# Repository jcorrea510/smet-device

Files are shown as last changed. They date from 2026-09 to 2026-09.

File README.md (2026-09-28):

# SMET rev3: parametric CadQuery rebuild

`SMET_rev3_assembly.stl` is a mesh of the whole simple-machines marble tower, with no CAD source.
`smet_rev3_assembly.py` rebuilds it as an editable CadQuery model. All dimensions are variables in
millimetres at the top of the file.

```bash
pip install -r requirements.txt
python smet_rev3_assembly.py   # writes output/smet_rev3_assembly.step and .stl
python compare.py              # checks the rebuild against the original, writes renders/
python motion_check.py         # collision + motion check for the wedge and the wheel & axle
```

* `output/smet_rev3_assembly.step`: 59 named, coloured parts (60 solids, because `fork_wheel` is two
  uprights). Import it into Onshape.
* `output/smet_rev3_assembly.stl`: one mesh for slicing and printing.
* `renders/`: side-by-side previews (original STL = blue, updated design = orange), the labelled
  `wedge_detail.png` and `winch_detail.png`, and `comparison_report.txt`.

## What's in the model

The tower is 312.0 × 304.8 × 757.0 mm overall (X × Y × Z). The base is 304.8 mm (12 in) square, and
marble 1 (arriving from the previous group) overhangs the left edge by 7.2 mm. The machines, top to bottom:

| Simple machine  | Parts |
|---|---|
| Pulley | `pulley` spool on `pulley_axle`, held by `pulley_arm` |
| Wedge | `wedge`, hung from the pulley string and jammed into the `top_ramp` (see below) |
| Screw | `spiral_upper` / `spiral_lower`: a 2-turn helical channel on three ¼ in dowels |
| Inclined planes | `entry_ramp`, `top_ramp`, `transfer_chute`, 6 `zigzag_ramp_*` |
| Wheel & axle | `paddle_wheel` + `string_drum` on a shared `wheel_axle`: a winch that tips the seesaw (see below) |
| Levers | `seesaw`, the counter-weighted `lever`, the tipping `cradle` + `rocker`, and the hinged `trapdoor` |

Every straight ramp shares one U-channel profile: 25.4 mm wide, 2 mm walls, 3.2 mm floor, walls 10 mm tall.

## How the machine runs

1. **Marble 1** comes from the previous group. It rolls down the `entry_ramp` (inclined plane) from the
   left edge of the base onto the `trapdoor` (lever).
2. The trap door tips and pulls a string over the `pulley` at the top. The other end of that string holds
   the `wedge`, which is jammed into the `top_ramp` in front of **marble 2**. The pull yanks the wedge up
   out of the ramp.
3. Marble 2 rolls down the `spiral` (screw), the `transfer_chute` and the six `zigzag_ramp`s (inclined
   planes).
4. Marble 2 drops into a cup on the **wheel & axle** and stays there. Its weight turns the wheel, and a
   drum on the same axle winds up a string that lifts the left end of the `seesaw` (lever).
5. The seesaw tips, and **marble 3**, which was waiting on it, rolls off onto the counter-weighted `lever`.
   That tips it into the `cradle` at the right edge, which hands it to the next group.

Each machine moves the next one. Marble 1 runs the trap door, which runs the pulley, which pulls the
wedge. Marble 2 runs the wheel & axle, which moves the seesaw.

## Redesign 1: the wedge (`VERTICAL_WEDGE`)

In the original, the wedge sat loose on the ramp floor, so it didn't really work as a wedge. Now it is a
small wooden wedge (12 mm thick, 20 mm tall, 17 mm wide at the bottom and 27 mm at the top) that hangs
straight down from the pulley string. Its sloping sides are jammed into the top ramp against the top
edges of the two side walls, and its flat face holds marble 2 back.

When marble 1 tips the trap door, the trap door drops about 22° onto its stop and pulls the string down
about 21 mm. The wedge only needs to rise about 15 mm to clear marble 2. Even fully raised, it still
stops about 2.5 mm below the pulley.

The wedge's weight is what holds the trap door level until marble 1 arrives. A wooden wedge on its own
(about 2.6 g) is too light for that. So there is a stack of washers (`wedge_weight`) on its string,
where the original design had a disc. **Tune it by hand:** add washers until the trap door stays up by
itself, then check that marble 1 still tips it. If the trap door is printed solid PLA, the wedge plus
washers needs to weigh about 21–30 g. A lower-infill trap door needs less.

The tall guide walls on the top ramp were only there for the old wedge, so they're gone.

## Redesign 2: the wheel & axle tips the seesaw (`WINCH_RELEASE`)

In the original, the paddle wheel spun loose on a pin. Marble 2 knocked it round and fell off onto the
feed ramp, so the wheel didn't pass any energy on (`renders/winch_detail.png`):

1. Marble 2 drops through the lowest zig-zag ramp into the left paddle. Each paddle now has a 7 mm lip at
   its tip, which makes a cup, so marble 2 stays on the wheel. Its weight turns the wheel. The marble
   can't spill out before about 83°, and the wheel never turns that far.
2. The wheel is glued to its axle, so the axle turns too. A small drum on the front of the axle (8 mm
   across) winds up a string.
3. The string runs down at an angle to a tab on the seesaw's left end and lifts that end. About 10° of
   wheel turn is enough to tip the seesaw past level. At about 45° the seesaw lands on its existing
   right-hand stop, and the string then holds the wheel still.
4. **Marble 3** was resting against a new end wall on the seesaw's left end. Its weight is what used to
   keep the seesaw down, so the seesaw's weight disc is gone. Marble 3 now rolls off the right end onto
   the lever and runs the rest of the machine.

The feed ramp (and its post) is removed, because nothing rolls from the wheel to the seesaw any more.
The wheel & axle now moves the seesaw itself.

Why it's a wheel & axle: marble 2 pushes on the wheel about 22 mm from the centre, and the string pulls
4.5 mm from it (the drum radius plus half the string). The wheel multiplies marble 2's pull almost
5 times. Lifting the seesaw's left end with marble 3 on it takes about 9.3 g of pull on the string, which
is more than marble 2 weighs (about 5.2 g). Marble 2 could not lift it with a plain string, but through
the wheel & axle it has about 2.7 times more force than it needs. (Estimates assume a solid-printed PLA
seesaw and ⅝ in glass marbles.)

**What to build.** New or changed pieces:

| Part | Material |
|---|---|
| `wedge` | small block of wood, cut to the wedge shape |
| `wedge_weight` | steel washers threaded on the string (tune the number) |
| `pulley_string_*`, `winch_string` | thread |
| `wheel_axle` | 3 mm bamboo skewer or steel rod, glued into the wheel and drum |
| `string_drum` | small 3D print (or a short piece of 5/16 in dowel with card flanges) |
| `paddle_wheel` | reprint of the existing wheel with the taller lips |
| `seesaw` | reprint with the new left end wall and string tab |
| `top_ramp` | the same ramp without the tall guide walls |

The rest of the model is unchanged, and nothing collides. `python motion_check.py` checks all of this:
- the trap door drops, lifts the wedge clear of marble 2 without hitting the pulley, and marble 2 rolls
  down to the spiral;
- marble 2 sits in the wheel's cup and the wheel turns;
- the seesaw tips onto its stop;
- marble 3 rolls off the seesaw onto the lever.

Set `VERTICAL_WEDGE = False` and `WINCH_RELEASE = False` to get the original design back.

## Adjustable dimensions (top of `smet_rev3_assembly.py`)

| Group | Variables | Default |
|---|---|---|
| Frame | `BASE_W`, `BASE_D`, `BASE_T` | 304.8, 304.8, 19.05 |
| | `POST_SIZE`, `FRAME_H` | 19.05, 757.001 |
| | `BACKING_T` (board between posts and ramps) | 11.05 |
| Channel profile | `CH_W`, `CH_WALL`, `CH_FLOOR`, `CH_WALL_H` | 25.4, 2.0, 3.2, 10.0 |
| | `END_WALL_T`, `END_WALL_H` | 2.0, 14.0 |
| Zig-zag ramps | `ZIG_COUNT`, `ZIG_TILT` (deg), `ZIG_LEN` | 6, 3.0, 290.8 |
| | `ZIG_DROP_HOLE`, `ZIG_Z0`, `ZIG_PITCH` (vertical spacing), `ZIG_X_INSET` | 20.8, 344.865, 39.039, 7.366 |
| Spiral | `SPIRAL_R_MID`, `SPIRAL_W`, `SPIRAL_PITCH` (drop per turn) | 80, 25.4, 35 |
| | `SPIRAL_INNER_WALL_H`, `SPIRAL_OUTER_WALL_H` | 8, 18 |
| | `SPIRAL_UPPER_SWEEP`, `SPIRAL_LOWER_SWEEP` (deg), `SPIRAL_TOP_Z` | 350, 340, 657.3 |
| | `TAB_W`, `TAB_R_IN`, `TAB_R_OUT`, `TAB_HOLE_D` | 12, 92.2, 108.5, 6.7 |
| Dowels | `DOWEL_D`, `DOWEL_R`, `DOWEL_ABOVE_TAB` | 6.35, 102, 4 |
| Pins / pivots | `PIN_D`, `PIVOT_HOLE_D`, `FORK_T`, `FORK_PIN_DROP` | 3.0, 3.5, 8.0, 4.0 |
| Paddle wheel | `WHEEL_R`, `WHEEL_HUB_D`, `WHEEL_PADDLE_T`, `WHEEL_PADDLES` | 32, 16, 2.4, 4 |
| Seesaw | `SEESAW_LEN`, `SEESAW_TILT`, `SEESAW_WEIGHT_D`, `SEESAW_WEIGHT_T` | 90, 1.0, 19, 1.52 |
| Lever | `LEVER_LEN`, `LEVER_BOX_H`, `LEVER_BOX_WALL`, `LEVER_WEIGHT_D`, `LEVER_WEIGHT_H` | 137, 13, 1, 19, 10.64 |
| Trap door | `TRAP_LEN`, `TRAP_KNUCKLE_R`, `TRAP_GATE_T`, `TRAP_STRING_HOLE_D` | 114, 3.5, 3.0, 1.8 |
| Other ramps | `FEED_TILT`/`FEED_LEN`, `ENTRY_TILT`/`ENTRY_LEN`, `TOP_TILT`/`TOP_LEN`, `TRANSFER_TILT`/`TRANSFER_LEN` | 5/95.965, −3/175.941, 3/159.218, 5/151.413 |
| Wedge | `VERTICAL_WEDGE`, `WEDGE_T`, `WEDGE_HEIGHT`, `WEDGE_HALF_ANGLE` (deg), `WEDGE_GAP` | True, 12, 20, 15, 1 |
| | `WEDGE_WEIGHT_D`, `WEDGE_WEIGHT_T`, `PULLEY_STRING_D` | 19, 3.04, 1.0 |
| | original block wedge: `WEDGE_H_LOW`, `WEDGE_H_HIGH` | 6, 18 |
| Pulley | `PULLEY_FLANGE_D`, `PULLEY_HUB_D`, `PULLEY_HUB_L`, `PULLEY_FLANGE_T` | 28, 20, 10, 1.5 |
| Winch | `WINCH_RELEASE`, `WHEEL_LIP_H`, `DRUM_D`, `DRUM_FLANGE_D`, `DRUM_L` | True, 7, 8, 16, 8 |
| | `AXLE_Y`, `DRUM_Y0`, `STRING_D` | (224, 286), 224, 1.0 |
| Seesaw (redesign) | `SEESAW_END_WALL_H`, `SEESAW_TAB_U`, `SEESAW_TAB_Y0` | 14, (−45, −39), 226 |
| Marbles | `MARBLE_D` | 15.875 (⅝ in) |

Positions are also variables: the `*_ANCHOR` points, the pivot coordinates and the `POSTS`, `STOP_POSTS`
and `FORKS` tables. The support posts are separate absolute coordinates. If you move a ramp or change its
tilt, update the post that holds it up, then re-run `compare.py` or check the renders.

## How close is the rebuild?

`compare.py` checks the rebuild against the original STL with both redesigns switched off, so the
check is not affected by them. From `renders/comparison_report.txt`:

* All 55 bodies in the original mesh match a rebuilt part. The worst bounding-box difference on any part is 0.007 mm.
* The overall bounding box matches to within 0.005 mm.
* Total volume is 3,406,020 mm³ vs 3,404,209 mm³ (+0.05%). All of the difference comes from true cylinders
  and spheres in the rebuild replacing the STL's faceted ones (12- to 24-sided pins, dowels and weights).

## Notes on the original mesh

* The zero-area one-triangle "bodies" and the open ends of the two spiral sections are not damage. The two
  sections share an end face, so a mesh split separates those triangles. The rebuild's STL does exactly the same.
* The lever's counterweight box is sealed with a 19 mm weight inside. In the STL the cavity shows up as a
  separate inside-out box.

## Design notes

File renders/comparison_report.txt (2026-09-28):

1. ORIGINAL DESIGN (WINCH_RELEASE=False, VERTICAL_WEDGE=False) vs the original STL
Original bodies: 55   Rebuilt parts: 55

part                   max bbox err     orig vol      new vol  vol err
backing_left                  0.000      44987.6      44987.6    0.00%
backing_right                 0.000      36963.0      36962.9   -0.00%
backstop_feed                 0.000       8980.2       8980.3    0.00%
backstop_left                 0.000      22708.6      22708.6   -0.00%
backstop_right                0.000      17073.0      17072.9   -0.00%
base                          0.000    1769802.6    1769802.9    0.00%
cradle                        0.007       1985.4       1984.1   -0.07%
cradle_pin                    0.000         94.5         99.0    4.72%
dowel_1                       0.002      19559.5      20071.4    2.62%
dowel_2                       0.002      19379.5      19886.7    2.62%
dowel_3                       0.002      19199.4      19701.9    2.62%
entry_ramp                    0.000      21338.1      21338.1    0.00%
feed_ramp                     0.000      11638.7      11638.6   -0.00%
fork_lever                    0.000      26391.9      26402.1    0.04%
fork_seesaw                   0.000      30073.5      30083.7    0.03%
fork_trapdoor                 0.000      16174.3      16183.3    0.06%
fork_wheel                    0.000      38116.9      38127.1    0.03%
lever                         0.000      20834.0      20827.8   -0.03%
lever_weight                  0.003       2982.4       3016.7    1.15%
marble_1                      0.005       2076.8       2094.8    0.87%
marble_2                      0.005       2076.8       2094.8    0.87%
paddle_wheel                  0.000       9950.5       9974.1    0.24%
post_cradle                   0.000      13014.0      13014.0   -0.00%
post_entry_ramp_1             0.000      17149.8      17149.8   -0.00%
post_entry_ramp_2             0.000      16722.2      16722.1   -0.00%
post_feed_ramp                0.000      16664.5      16664.5   -0.00%
post_left                     0.000     267804.1     267804.3    0.00%
post_lever_box                0.000      18187.1      18187.1    0.00%
post_lever_rest               0.000      17746.3      17746.4    0.00%
post_right                    0.000     267804.0     267804.3    0.00%
post_top_ramp                 0.000      46543.2      46543.2    0.00%
post_trap_stop                0.000       6514.8       6514.9    0.00%
pulley                        0.004       4848.8       4863.8    0.31%
pulley_arm                    0.000      10077.0      10075.0   -0.02%
pulley_axle                   0.000        459.0        480.7    4.72%
rocker                        0.000       1030.4       1032.5    0.20%
seesaw                        0.000      11794.6      11788.4   -0.05%
seesaw_stop_left              0.000      11255.6      11255.6    0.00%
seesaw_stop_right             0.000      11104.9      11104.9   -0.00%
seesaw_weight                 0.003        426.1        431.0    1.15%
spiral (both sections)        0.002     134100.5     134203.8    0.08%
top_beam                      0.000      96786.0      96786.1    0.00%
top_ramp                      0.001      23420.8      23420.8   -0.00%
transfer_chute                0.003      17726.5      17726.6    0.00%
trap_latch_post               0.000      12195.7      12195.7   -0.00%
trapdoor                      0.001      16129.7      16131.0    0.01%
wedge                         0.000       4320.0       4320.0   -0.00%
wedge_disc                    0.003        852.1        861.9    1.15%
wheel_stop_pin                0.000      14080.2      14089.2    0.06%
zigzag_ramp_1                 0.002      33844.1      33843.8   -0.00%
zigzag_ramp_2                 0.002      33844.1      33843.8   -0.00%
zigzag_ramp_3                 0.002      33844.1      33843.8   -0.00%
zigzag_ramp_4                 0.002      33844.1      33843.8   -0.00%
zigzag_ramp_5                 0.002      33843.9      33843.8   -0.00%
zigzag_ramp_6                 0.002      33844.1      33843.8   -0.00%

Worst per-part bounding-box deviation: 0.007 mm

Overall            original STL             rebuild
bbox min   [-7.222  0.     0.   ]   [-7.217  0.     0.   ]
bbox max   [304.8   304.8   757.001] [304.8   304.8   757.001]
volume     3,404,209 mm^3          3,406,020 mm^3  (+0.053%)

2. REDESIGN (wheel & axle tips the seesaw, wedge hangs from the pulley)
added:   wedge_weight, pulley_string_wedge, pulley_string_trapdoor, wheel_axle, string_drum, winch_string, marble_3
changed: top_ramp, wedge, paddle_wheel, fork_wheel, seesaw, marble_2
removed: wedge_disc, feed_ramp, seesaw_weight, post_feed_ramp
46 of 56 original parts are untouched

wrote renders/compare_*.png

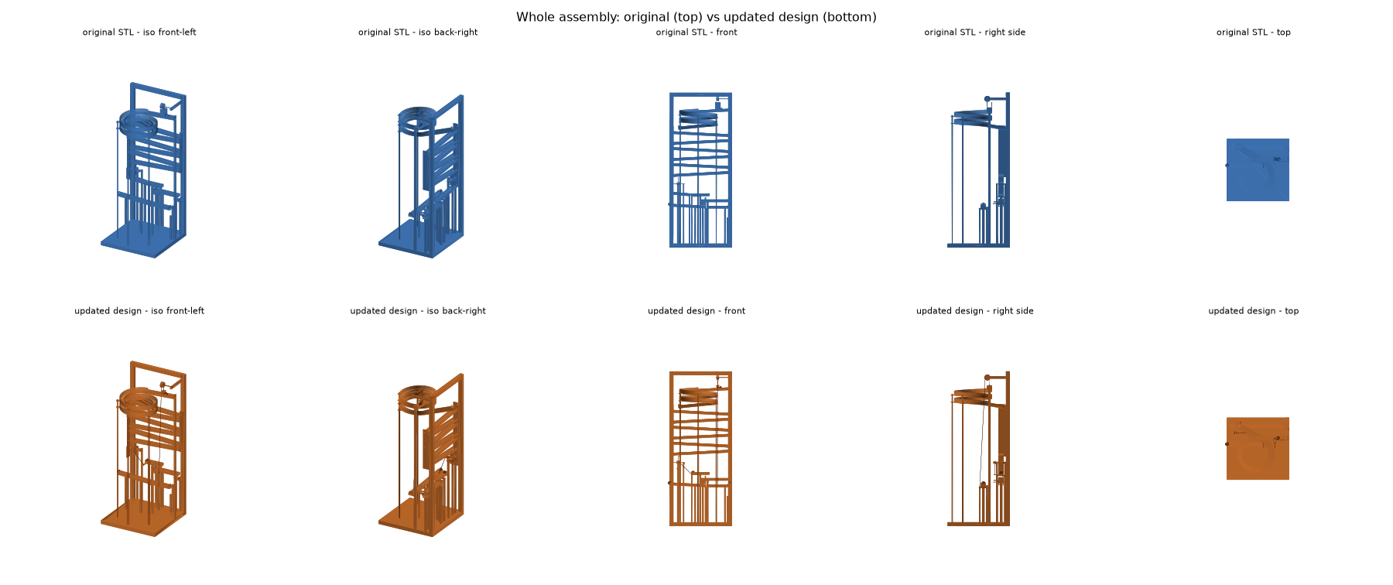
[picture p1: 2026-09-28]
renders/compare_overview.png

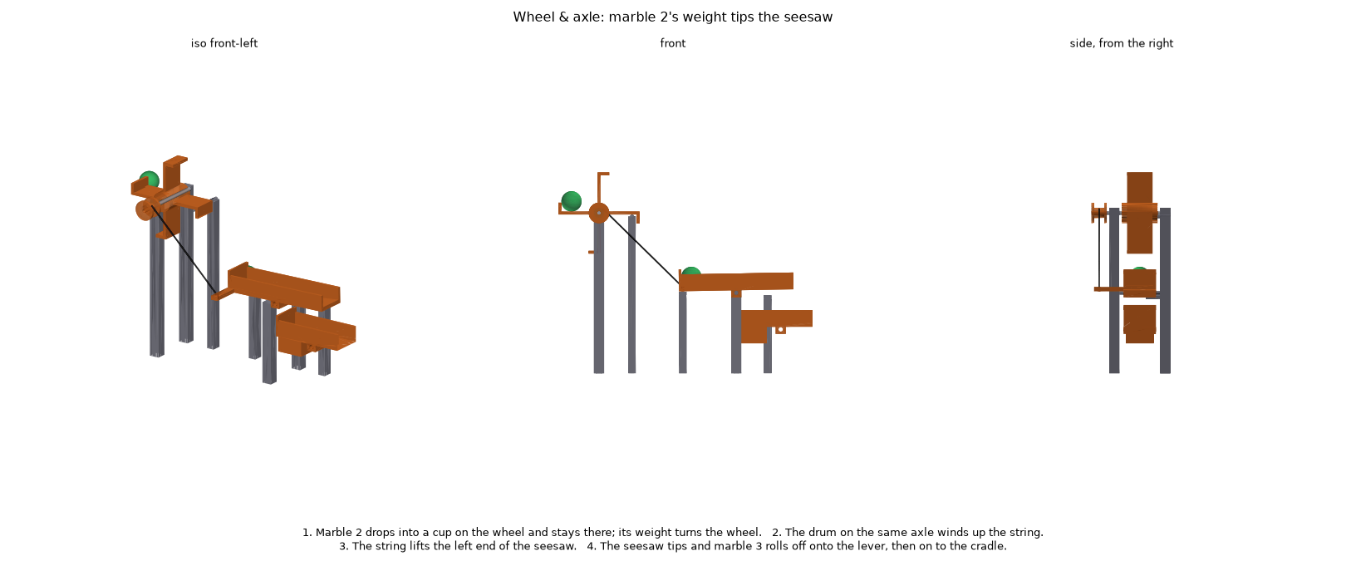
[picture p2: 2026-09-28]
renders/winch_detail.png

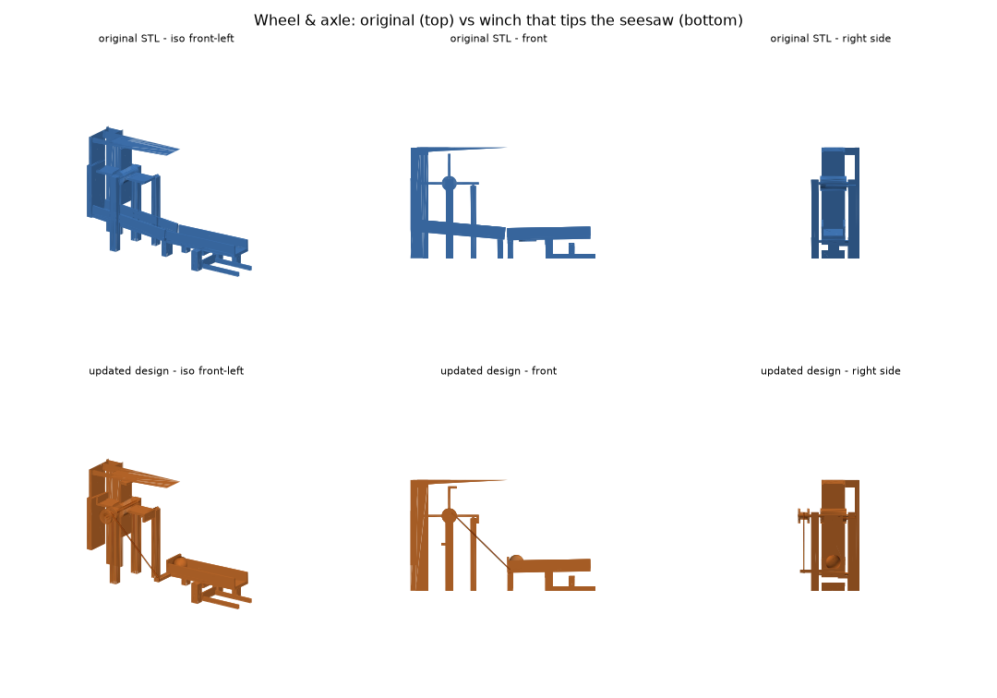
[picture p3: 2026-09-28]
renders/compare_wheel_axle.png

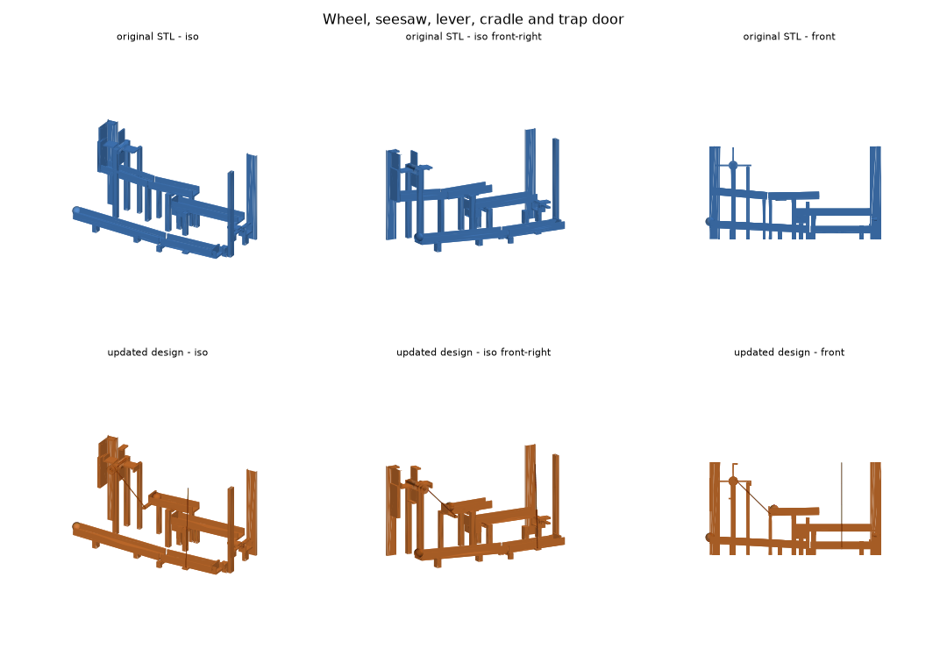
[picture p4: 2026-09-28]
renders/compare_mechanisms.png

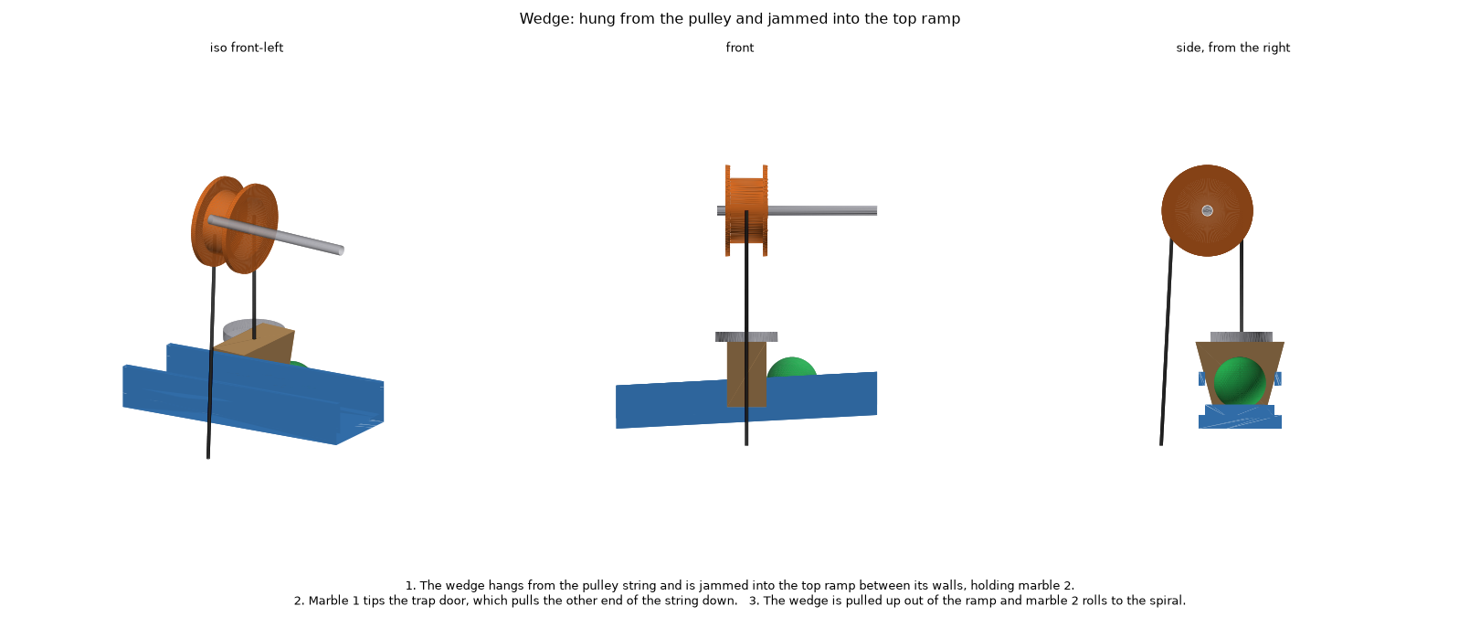
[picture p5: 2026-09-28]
renders/wedge_detail.png

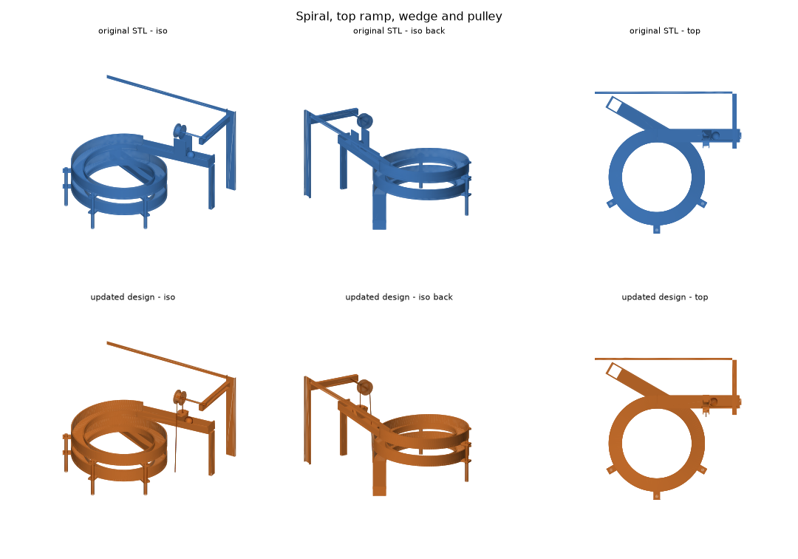
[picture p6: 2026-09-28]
renders/compare_spiral_top.png

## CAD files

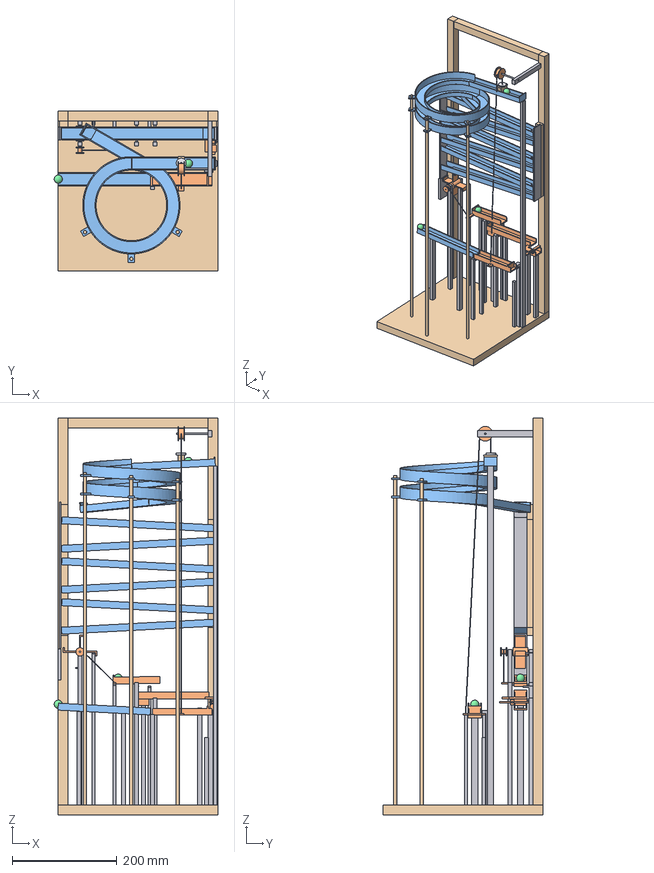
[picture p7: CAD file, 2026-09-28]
output/smet_rev3_assembly.step
312.0 x 304.8 x 757.0 mm
base
post_left
post_right
top_beam
backing_left
backing_right
backstop_left
backstop_right
backstop_feed
zigzag_ramp_1
zigzag_ramp_2
zigzag_ramp_3
zigzag_ramp_4
zigzag_ramp_5
zigzag_ramp_6
spiral_upper
spiral_lower
dowel_1
dowel_2
dowel_3
transfer_chute
top_ramp
wedge
wedge_weight
pulley_string_wedge
pulley_string_trapdoor
pulley
pulley_axle
pulley_arm
paddle_wheel
wheel_axle
string_drum
winch_string
fork_wheel
fork_seesaw
fork_lever
fork_trapdoor
wheel_stop_pin
seesaw
lever
lever_weight
cradle
rocker
cradle_pin
trapdoor
entry_ramp
post_top_ramp
post_lever_box
post_lever_rest
post_entry_ramp_1
post_entry_ramp_2
post_cradle
post_trap_stop
seesaw_stop_left
seesaw_stop_right
trap_latch_post
marble_1
marble_2
marble_3

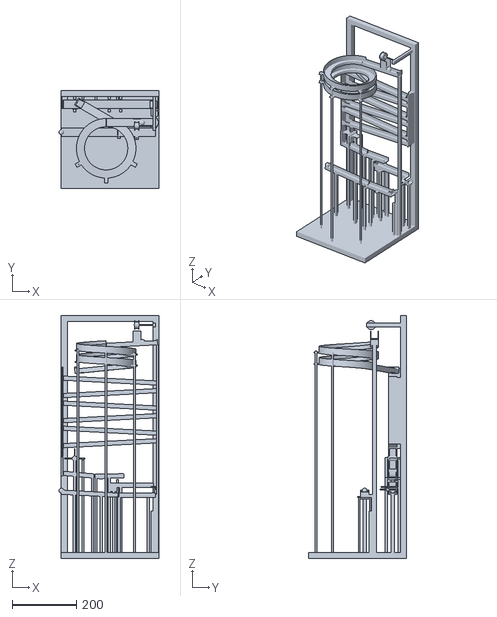
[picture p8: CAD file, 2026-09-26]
SMET_rev3_assembly.stl
312.0 x 304.8 x 757.0

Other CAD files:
output/smet_rev3_assembly.stl

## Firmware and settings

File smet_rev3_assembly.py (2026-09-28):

"""
SMET rev3 simple-machines marble tower -- parametric CadQuery rebuild.

Rebuilt from SMET_rev3_assembly.stl (the original mesh had no CAD source).
Two redesigns, both on by default:
  WINCH_RELEASE  -- marble 2 stays in a cup on the paddle wheel; the wheel's
                    axle winds a string that tips the seesaw, which rolls
                    marble 3 onto the lever.
  VERTICAL_WEDGE -- the wedge hangs from the pulley string and is jammed into
                    the top ramp; the trap door pulls it up to free marble 2.
Set both to False to get the original design back.
Every dimension is in millimetres.  Edit the variables in the PARAMETERS
section below and re-run:

    python smet_rev3_assembly.py

Outputs (written to ./output/):
    smet_rev3_assembly.step   named parts, for importing into Onshape
    smet_rev3_assembly.stl    single mesh, for 3D printing / slicing

Coordinate system (same as the original STL):
    X = left -> right across the base
    Y = front -> back (the two tall posts are at the back, high Y)
    Z = up, Z = 0 is the underside of the base board
"""

import math
import os

import cadquery as cq

# =============================================================================
# PARAMETERS  (millimetres / degrees)
# =============================================================================

# ---- Frame ------------------------------------------------------------------
BASE_W = 304.8          # base board width  (X) -- 12 in
BASE_D = 304.8          # base board depth  (Y) -- 12 in
BASE_T = 19.05          # base board thickness  -- 3/4 in
POST_SIZE = 19.05       # square section of the two back posts and top beam
FRAME_H = 757.001       # overall height, floor to top of the top beam

# Backing boards on the front face of each post (ramps mount to these)
BACKING_T = 11.05               # thickness in Y
BACKING_L_X0 = 2.8              # left backing board: X start
BACKING_L_Z = (341.998, 592.538)
BACKING_R_X1 = 302.0            # right backing board: X end
BACKING_R_Z = (357.343, 563.193)

# Thin backstop plates at the ends of the zig-zag ramps
BACKSTOP_T = 3.2
BACKSTOP_L_X0 = 2.8
BACKSTOP_L_Z = (317.151, 596.538)
BACKSTOP_R_X0 = 298.8
BACKSTOP_R_Z = (357.143, 567.193)
LOWER_BACKSTOP_X = (0.0, 6.0)       # stop at the end of the feed ramp
LOWER_BACKSTOP_Z = (257.725, 316.651)

# ---- Common U-channel ramp profile (used by every straight ramp) --------------
CH_W = 25.4             # outside width -- 1 in
CH_WALL = 2.0           # side wall thickness
CH_FLOOR = 3.2          # floor thickness
CH_WALL_H = 10.0        # side wall height above the floor surface
END_WALL_T = 2.0        # thickness of closed end walls
END_WALL_H = 14.0       # standard closed end wall height above the floor

# Y position of the main ramp line (back ramps run against the backing boards)
RAMP_Y0 = BASE_D - POST_SIZE - BACKING_T - CH_W   # = 249.3 front edge of channel

# ---- Zig-zag inclined planes (6 ramps) --------------------------------------
ZIG_COUNT = 6
ZIG_TILT = 3.0          # degrees
ZIG_LEN = 290.8         # length along the slope
ZIG_DROP_HOLE = 20.8    # floor opening at the low end where the marble drops
ZIG_X_INSET = 7.366     # base edge -> bottom corner of the low end
ZIG_Z0 = 344.865        # bottom corner (low end) of the lowest ramp
ZIG_PITCH = 39.039      # vertical spacing between ramps

# ---- Spiral ("screw") -------------------------------------------------------
SPIRAL_CX, SPIRAL_CY = 140.0, 125.0   # helix axis
SPIRAL_R_MID = 80.0     # centre radius of the channel
SPIRAL_W = 25.4         # channel width (radial)
SPIRAL_PITCH = 35.0     # drop per full turn
SPIRAL_INNER_WALL_H = 8.0    # inner wall height above floor
SPIRAL_OUTER_WALL_H = 18.0   # outer (banked) wall height above floor
SPIRAL_TOP_ANGLE = 90.0      # angle where the marble enters (deg, CCW from +X)
SPIRAL_TOP_Z = 657.3         # floor underside at the entry
SPIRAL_UPPER_SWEEP = 350.0   # first printed section
SPIRAL_LOWER_SWEEP = 340.0   # second printed section
# Mounting tabs (3 per section) that slide over the dowels
TAB_ANGLES = (210.0, 270.0, 330.0)
TAB_W = 12.0
TAB_R_IN = 92.2
TAB_R_OUT = 108.5
TAB_HOLE_D = 6.7
# Dowels holding up the spiral
DOWEL_D = 6.35          # 1/4 in
DOWEL_R = 102.0         # radius of the dowel circle about the helix axis
DOWEL_ABOVE_TAB = 4.0   # dowel sticks up this far above the top tab

# ---- Pins and pivots --------------------------------------------------------
PIN_D = 3.0             # axle / pin diameter
PIVOT_HOLE_D = 3.5      # clearance hole for pins
FORK_T = 8.0            # thickness (X) of the pivot fork uprights
FORK_PRONG = 8.0        # prong depth (Y) for the back-row forks
FORK_PIN_DROP = 4.0     # pin centre below fork top

# ---- Wheel & axle (paddle wheel) --------------------------------------------
WHEEL_CX, WHEEL_CZ = 42.0, 311.151
WHEEL_Y = (248.0, 276.0)       # hub length along Y
WHEEL_HUB_D = 16.0
WHEEL_R = 32.0                 # paddle tip radius
WHEEL_PADDLE_T = 2.4
WHEEL_PADDLE_Y = (252.0, 272.0)
WHEEL_PADDLES = 4

# ---- Wheel & axle winch (redesign) --------------------------------------------
# True  = marble 2 drops into a cup on the wheel and stays there.  Its weight
#         turns the wheel; the drum on the same axle winds a string that lifts
#         the left end of the seesaw, so marble 3 (waiting on the seesaw) rolls
#         off onto the lever.  The feed ramp is no longer needed.
# False = the original passive paddle wheel (loose on a fixed pin).
WINCH_RELEASE = True
WHEEL_LIP_H = 7.0               # cup lip on each paddle tip (holds marble 2)
AXLE_Y = (224.0, 286.0)         # rotating axle (PIN_D bamboo skewer or rod)
DRUM_Y0 = 224.0                 # front face of the string drum
DRUM_D = 8.0                    # winding diameter -- the "axle" of the wheel & axle
DRUM_FLANGE_D = 16.0
DRUM_FLANGE_T = 2.0
DRUM_L = 8.0                    # winding length between the flanges
STRING_D = 1.0
SEESAW_END_WALL_H = 14.0        # new end wall at the seesaw's left end (marble 3 rests on it)
SEESAW_TAB_U = (-45.0, -39.0)   # string tab position along the seesaw (from its pivot)
SEESAW_TAB_Y0 = 226.0           # the tab reaches forward to here, under the drum

# ---- Feed ramp (5 deg) between wheel and seesaw ------------------------------
FEED_TILT = 5.0
FEED_LEN = 95.965
FEED_ANCHOR = (6.121, RAMP_Y0, 258.702)     # bottom corner at high (left) end

# ---- Seesaw (lever on pivot) -------------------------------------------------
SEESAW_PIVOT = (150.0, 248.312)     # (x, z) of the pin
SEESAW_TILT = 1.0
SEESAW_LEN = 90.0
SEESAW_BLOCK_W = 8.0
SEESAW_BLOCK_BELOW = 3.5            # pivot block extends this far below pin
SEESAW_FLOOR_ABOVE = 2.0            # floor underside above pin centre
SEESAW_WEIGHT_D = 19.0
SEESAW_WEIGHT_T = 1.52
SEESAW_WEIGHT_U = -23.0             # weight position along the seesaw

# ---- Counter-weighted lever -------------------------------------------------
LEVER_X0 = 151.0
LEVER_LEN = 137.0
LEVER_Z0 = 221.549                  # underside of lever floor
LEVER_PIVOT_X = 185.0
LEVER_BLOCK_BELOW = 3.5             # pivot block extends this far below pin
LEVER_BOX = (152.0, 251.0, 174.0, 273.0)   # counterweight box x0,y0,x1,y1
LEVER_BOX_H = 13.0
LEVER_BOX_WALL = 1.0
LEVER_WEIGHT_D = 19.0
LEVER_WEIGHT_H = 10.64
LEVER_TAB_X = (280.0, 302.0)
LEVER_TAB_Y = (226.3, 240.3)

# ---- Tipping cradle + rocker ------------------------------------------------
CRADLE_ANCHOR = (289.935, RAMP_Y0, 200.301)
CRADLE_LEN = 14.5
CRADLE_TILT = -1.146
CRADLE_PIN_Y, CRADLE_PIN_Z = 246.0, 214.898
CRADLE_EAR_X = ((290.0, 292.0), (300.0, 302.0))
CRADLE_EAR_Y0 = 242.7
CRADLE_EAR_H = 10.0
ROCKER_X = (293.0, 299.0)
ROCKER_Y = (222.0, 278.0)
ROCKER_T = 3.0
ROCKER_HUB_D = 6.4
CRADLE_PIN_X = (289.0, 303.0)

# ---- Trap-door lever (hinged channel) ----------------------------------------
TRAP_X0 = 180.0
TRAP_LEN = 114.0
TRAP_Y0 = 162.3
TRAP_Z0 = 190.276
TRAP_KNUCKLE_R = 3.5
TRAP_HINGE_Z = 188.276
TRAP_GATE_X = 284.0
TRAP_GATE_T = 3.0
TRAP_LATCH_TAB = (286.0, 187.7, 296.0, 195.5)
TRAP_STRING_TAB = (230.0, 152.5, 240.0, 162.3)
TRAP_STRING_HOLE_D = 1.8

# ---- Entry ramp (marble 1 arrives here from the previous group) ----------------
ENTRY_TILT = -3.0
ENTRY_LEN = 175.941
ENTRY_ANCHOR = (0.133, TRAP_Y0, 199.989)

# ---- Top ramp, wedge and pulley ---------------------------------------------
TOP_TILT = 3.0
TOP_LEN = 159.218
TOP_ANCHOR = (141.167, 192.3, 657.355)
TOP_CHUTE_X = (223.0, 249.0)
TOP_CHUTE_TOP = 709.001
WEDGE = (227.0, 195.0, 245.0, 215.0)   # x0, y0, x1, y1
WEDGE_Z0 = 667.001
WEDGE_H_LOW, WEDGE_H_HIGH = 6.0, 18.0
WEDGE_DISC_D, WEDGE_DISC_T = 19.0, 3.04
WEDGE_DISC_C = (235.4, 205.0, 677.801)

# Wedge redesign: True = a wooden wedge hangs straight down from the pulley
# string and is jammed (wedged) into the top ramp between its side walls,
# holding marble 2.  When the trap door pulls the string, the wedge is pulled
# up out of the ramp.  False = the original block wedge on the ramp floor.
VERTICAL_WEDGE = True
WEDGE_T = 12.0              # thickness along the ramp, centred under the pulley
WEDGE_HEIGHT = 20.0
WEDGE_HALF_ANGLE = 15.0     # taper of each side face
WEDGE_GAP = 1.0             # clearance under the wedge while it is jammed
PULLEY_STRING_D = 1.0
# Washers stacked on the wedge's string.  The wedge's weight is what holds the
# trap door level, so add or remove washers until the trap door just stays up
# by itself and tips when marble 1 rolls onto it.
WEDGE_WEIGHT_D, WEDGE_WEIGHT_T, WEDGE_WEIGHT_HOLE = 19.0, 3.04, 3.0

PULLEY_Y, PULLEY_Z = 195.0, 727.001
PULLEY_X0 = 228.5
PULLEY_FLANGE_D, PULLEY_FLANGE_T = 28.0, 1.5
PULLEY_HUB_D, PULLEY_HUB_L = 20.0, 10.0
PULLEY_AXLE_X = (226.0, 294.0)
PULLEY_ARM = (286.0, 180.0, 294.0, 721.001)    # x0, y0, x1, z0
PULLEY_ARM_H = 12.0

# ---- Transfer chute (spiral exit -> top zig-zag ramp) -------------------------
TRANSFER_ANCHOR = (42.744, 258.862, 576.978)   # bottom corner at low end
TRANSFER_YAW = -30.0
TRANSFER_TILT = 5.0
TRANSFER_LEN = 151.413
TRANSFER_END_WALL_H = 16.0
TRANSFER_DROP_HOLE = 20.0

# ---- Marbles ----------------------------------------------------------------
MARBLE_D = 15.875       # 5/8 in
MARBLE_1 = (0.716, 175.0, 211.111)     # arriving from the previous group
MARBLE_2 = (252.938, 205.0, 674.366)   # waiting behind the wedge at the top

# ---- Simple support posts: name -> (x0, y0, x1, y1, z_top) ------------------
POSTS = {
    "post_top_ramp": (297.0, 199.0, 303.0, 211.0, 665.484),
    "post_lever_box": (159.0, 256.0, 167.0, 268.0, 208.499),
    "post_lever_rest": (266.402, 256.0, 274.402, 268.0, 203.908),
    "post_entry_ramp_1": (36.0, 169.0, 44.0, 181.0, 197.694),
    "post_entry_ramp_2": (121.0, 169.0, 129.0, 181.0, 193.239),
    "post_feed_ramp": (94.0, 256.0, 100.0, 268.0, 250.501),
    "post_cradle": (294.0, 256.0, 300.0, 268.0, 199.8),
    "post_trap_stop": (279.602, 188.7, 287.049, 195.5, 147.703),
}
# Posts with a flat stop plate on top: name -> (x0, x1, post_y0, plate_y0, y1, z_top, plate_t)
STOP_POSTS = {
    "seesaw_stop_left": (105.006, 111.006, 278.0, 267.0, 286.0, 246.535, 2.95),
    "seesaw_stop_right": (171.757, 177.757, 278.0, 267.0, 286.0, 243.395, 2.95),
}
TRAP_LATCH_POST = (286.0, 296.0, 196.5, 188.7, 203.0, 193.476, 6.0)

# Pivot forks: name -> (x0, [(y0, y1), ...], z_top, pin_z, pin_y_range)
FORKS = {
    "fork_wheel": (38.0, [(238.0, 246.0), (278.0, 286.0)], 315.151, None, None),
    "fork_seesaw": (146.0, [(238.0, 246.0), (278.0, 286.0)], 252.312, None, None),
    "fork_lever": (181.0, [(238.0, 246.0), (278.0, 286.0)], 223.549, None, None),
    "fork_trapdoor": (176.0, [(155.0, 160.8), (189.2, 195.0)], 191.276, 188.276, None),
    "wheel_stop_pin": (65.0, [(278.0, 286.0)], 308.451, 308.451, (254.0, 286.0)),
}
WHEEL_STOP_T = 6.0      # the wheel-stop post is 6 mm wide instead of FORK_T


# =============================================================================
# HELPERS
# =============================================================================

def box(x0, y0, z0, x1, y1, z1):
    """Axis-aligned box between two corners."""
    return (cq.Workplane("XY")
            .box(x1 - x0, y1 - y0, z1 - z0, centered=False)
            .translate((x0, y0, z0)))


def cyl(d, p0, axis, length):
    """Cylinder of diameter d starting at p0 running `length` along `axis`."""
    return cq.Workplane("XY").add(
        cq.Solid.makeCylinder(d / 2.0, length, cq.Vector(*p0), cq.Vector(*axis)))


def place(wp, anchor, pitch=0.0, yaw=0.0):
    """Tilt a part built in local coordinates (+X along its length) up by
    `pitch` degrees, turn it `yaw` degrees about Z, and move its origin to
    `anchor`."""
    if pitch:
        wp = wp.rotate((0, 0, 0), (0, 1, 0), -pitch)
    if yaw:
        wp = wp.rotate((0, 0, 0), (0, 0, 1), yaw)
    return wp.translate(anchor)


def channel(length, *, end_wall_start=None, end_wall_end=None,
            hole_start=None, hole_end=None, width=CH_W):
    """Straight U-channel in local coordinates.

    Origin at the bottom corner of the start end; +X along the channel,
    +Y across it, +Z up.  end_wall_* is the end wall height above the floor
    surface (None = open end).  hole_* = (offset, length) of a drop hole cut
    through the floor between the walls, measured from that end."""
    h = CH_FLOOR + CH_WALL_H
    ch = box(0, 0, 0, length, width, h).cut(
        box(-1, CH_WALL, CH_FLOOR, length + 1, width - CH_WALL, h + 1))
    if end_wall_start is not None:
        ch = ch.union(box(0, 0, 0, END_WALL_T, width, CH_FLOOR + end_wall_start))
    if end_wall_end is not None:
        ch = ch.union(box(length - END_WALL_T, 0, 0, length, width,
                          CH_FLOOR + end_wall_end))
    if hole_start is not None:
        off, ln = hole_start
        ch = ch.cut(box(off, CH_WALL, -1, off + ln, width - CH_WALL, CH_FLOOR + 1))
    if hole_end is not None:
        off, ln = hole_end
        ch = ch.cut(box(length - off - ln, CH_WALL, -1, length - off,
                        width - CH_WALL, CH_FLOOR + 1))
    return ch


def helical_channel(sweep_deg, top_angle, top_z):
    """One section of the spiral: a U-channel swept along a descending helix.

    Starts (high end) at `top_angle` with the floor underside at `top_z`
    and descends counter-clockwise (seen from above) by SPIRAL_PITCH/turn."""
    r0 = SPIRAL_R_MID - SPIRAL_W / 2
    r1 = SPIRAL_R_MID + SPIRAL_W / 2
    pts = [
        (r0, 0), (r1, 0),
        (r1, CH_FLOOR + SPIRAL_OUTER_WALL_H), (r1 - CH_WALL, CH_FLOOR + SPIRAL_OUTER_WALL_H),
        (r1 - CH_WALL, CH_FLOOR), (r0 + CH_WALL, CH_FLOOR),
        (r0 + CH_WALL, CH_FLOOR + SPIRAL_INNER_WALL_H), (r0, CH_FLOOR + SPIRAL_INNER_WALL_H),
    ]
    height = SPIRAL_PITCH * sweep_deg / 360.0
    # A left-handed helix climbs clockwise, i.e. it descends counter-clockwise.
    helix = cq.Wire.makeHelix(SPIRAL_PITCH, height, SPIRAL_R_MID, lefthand=True)
    solid = (cq.Workplane("XZ").polyline(pts).close()
             .sweep(cq.Workplane().add(helix), isFrenet=True))
    low_angle = top_angle + sweep_deg        # where the section ends (low end)
    low_z = top_z - height
    return (solid.rotate((0, 0, 0), (0, 0, 1), low_angle)
            .translate((SPIRAL_CX, SPIRAL_CY, low_z)))


def spiral_floor_z(angle_from_top):
    """Floor underside height of the spiral `angle_from_top` deg after entry."""
    return SPIRAL_TOP_Z - SPIRAL_PITCH * angle_from_top / 360.0


def spiral_tab(angle, z):
    tab = box(TAB_R_IN, -TAB_W / 2, 0, TAB_R_OUT, TAB_W / 2, CH_FLOOR).cut(
        cyl(TAB_HOLE_D, (DOWEL_R, 0, -1), (0, 0, 1), CH_FLOOR + 2))
    return (tab.rotate((0, 0, 0), (0, 0, 1), angle)
            .translate((SPIRAL_CX, SPIRAL_CY, z)))


def angle_after(start, a):
    """Degrees travelled (CCW) from `start` to angle `a`, in [0, 360)."""
    return (a - start) % 360.0


# =============================================================================
# BUILD
# =============================================================================
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

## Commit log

2026-09-26 Add parametric CadQuery rebuild of SMET rev3 assembly
    Recreate the SMET_rev3_assembly.stl marble tower as an editable CadQuery
    model with every key dimension exposed as a named variable (mm).
    - smet_rev3_assembly.py: builds 56 named parts and exports STEP (for
    Onshape) and STL (for printing) to output/
    - compare.py: matches each original mesh body to a rebuilt part, compares
    bounding boxes and volumes, and renders side-by-side previews to renders/
    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
    [smet_rev3_assembly.step, smet_rev3_assembly.stl]
2026-09-28 Turn the wheel & axle into a winch that releases marble 2
    The paddle wheel used to spin loose on a fixed pin, so marble 1 just tipped
    it and fell off without transferring energy. The wheel is now a working
    wheel & axle:
    - paddle_wheel is fixed to a rotating 3 mm wheel_axle (fork_wheel gets
    bearing holes instead of a fixed pin; new axle_bearing_post at the front)
    and its paddles have lips so marble 1 rides the wheel down
    - a 16 mm string_drum on the same axle winds a winch_string
    - the string tips a new release_tray (on fork_release_tray, with pivot and
    rest pins) above the exit ramp, rolling marble 2 onto the exit ramp
    - WINCH_RELEASE = False restores the original design; compare.py s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
    [smet_rev3_assembly.step, smet_rev3_assembly.stl]
2026-09-28 Rework wheel & axle so marble 3 runs the bottom half of the machine
    The previous winch released a marble onto the entry ramp, which only
    re-fired the trap door that marble 1 (from the previous group) had
    already triggered. The run order is now:
    marble 1 -> entry ramp -> trap door -> pulley lifts wedge
    marble 2 -> spiral -> zig-zag ramps -> wheel & axle
    marble 3 -> feed ramp -> seesaw -> lever -> cradle -> next group
    - marble 2 drops into a cupped paddle (7 mm lips) and stays; its weight
    turns the wheel ~80 deg to the existing stop pin
    - a 14 mm drum on the wheel's axle winds a string that lifts the front of
    a wooden release lever (pivoting on a nail in the fork upright); the
    le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
    [smet_rev3_assembly.step, smet_rev3_assembly.stl]
2026-09-28 Hang the wedge from the pulley and make the wheel & axle tip the seesaw
    Wedge (VERTICAL_WEDGE): the wedge is now a wooden wedge hanging from the
    pulley string, jammed into the top ramp between its side walls in front
    of marble 2. The trap door pulls it up ~21 mm (15 mm needed). Washers on
    its string balance the trap door. The top ramp's old guide walls and the
    wedge disc are removed.
    Wheel & axle (WINCH_RELEASE): marble 2 stays in the wheel's cup; the
    8 mm drum on its axle winds a string to a tab on the seesaw's left end
    and lifts it, so marble 3 (now waiting on the seesaw against a new end
    wall) rolls onto the lever. The feed ramp, its post, the seesaw weight
    and the peg release lever are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
    [smet_rev3_assembly.step, smet_rev3_assembly.stl]
